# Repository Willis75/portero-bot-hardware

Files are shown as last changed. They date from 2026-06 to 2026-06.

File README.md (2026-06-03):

# Portero Bot — Hardware V2

Custom PCB and ESP32 firmware for the Claustro4 gate controller system.

## Overview

Replaces the Raspberry Pi Pico + protoboard + commercial relay board with a professional custom PCB.

- **MCU:** ESP32-WROOM-32E
- **Ethernet:** W5500 (SPI) + HanRun HR911105A RJ45
- **Relays:** 3× dry contact (simulates button press on gate opener controllers)
- **Power:** 9-24V DC barrel jack → 5V buck → 3.3V LDO
- **Programming:** MicroUSB (first flash) + OTA over Ethernet (updates)

## Repository Structure

```
hardware/       KiCad schematic + PCB layout + Gerber files
firmware/       PlatformIO ESP32 firmware (C++)
docs/           BOM, schematic reference, Flux.ai prompt
```

## API

The ESP32 exposes an HTTP API compatible with the existing Node.js bot (no changes required):

```
POST /abrir/vehicular_entrada
POST /abrir/vehicular_salida
POST /abrir/peatonal
GET  /healthz
POST /update   (OTA firmware upload)
```

## Related

- Bot: [Willis75/Portero-bot-telegram](https://github.com/Willis75/Portero-bot-telegram)
- Fabrication: JLCPCB PCBA (~$126 USD / 5 units)

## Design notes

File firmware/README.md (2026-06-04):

# portero-bot V2 firmware

Firmware ESP32 para hardware V2 (PCB custom con W5500 Ethernet + 3 relés).

## Setup primera vez

1. **Instalar PlatformIO**:
   ```
   pip install platformio
   ```
   O instalar extensión PlatformIO en VSCode.

2. **Crear `include/config.h`** copiando `config.example.h`:
   ```
   cp include/config.example.h include/config.h
   ```

3. **Llenar credenciales** en `include/config.h`:
   - `API_TOKEN`: generar con `openssl rand -hex 32`
   - `WIFI_SSID` / `WIFI_PASSWORD`: red WiFi backup
   - `ETH_STATIC_IP`: IP fija para Ethernet en la red del condominio
   - `OTA_USERNAME` / `OTA_PASSWORD`: para subir firmware OTA
   - `HEALTHCHECK_URL`: opcional (healthchecks.io)

4. **Build + flash via USB** (primera vez):
   ```
   cd firmware/
   pio run --target upload --upload-port COM4   # ajustar COM port
   pio device monitor
   ```

5. **Después flash via OTA** (sin desconectar):
   - Web UI: http://192.168.1.50/update
   - O CLI: `pio run --target upload --upload-protocol espota --upload-port 192.168.1.50`

## API HTTP

Todos los `POST` requieren header `Authorization: Bearer <API_TOKEN>`.

| Método | Endpoint | Función |
|---|---|---|
| POST | `/api/gate/entrada` | Activa relé K1 (portón entrada) |
| POST | `/api/gate/salida` | Activa relé K2 (portón salida) |
| POST | `/api/gate/peatonal` | Activa relé K3 (portón peatonal) |
| GET  | `/api/status` | Healthcheck JSON (uptime, IP, heap, rssi) |
| POST | `/api/restart` | Reset suave del ESP32 |
| GET  | `/update` | UI web OTA (basic auth) |

### Ejemplo curl

```bash
TOKEN="tu_token_de_32_bytes_hex"
curl -X POST -H "Authorization: Bearer $TOKEN" http://192.168.1.50/api/gate/entrada
# Response: {"status":"ok","gate":"entrada","uptime_s":12345}

curl http://192.168.1.50/api/status
# Response: {"uptime_s":12345,"eth":true,"wifi":false,"ip":"192.168.1.50","heap_free":234567,...}
```

## 24/7 Features

- **Brownout detector** (2.43V) → reset si rail 3.3V baja
- **Task Watchdog** (5s) → reset si firmware hang
- **Ethernet primary + WiFi fallback** automático
- **Static IP** (no depende DHCP)
- **Cooldown 2s** entre activaciones del mismo relé (evita re-trigger accidental)
- **Pulse 500ms** simula presión de botón
- **OTA con rollback** (AsyncElegantOTA)
- **Healthchecks.io ping** cada 60s para detectar offline

## Hardware pin map (NO modificar)

```
GPIO 32 → RELAY1 (entrada)
GPIO 33 → RELAY2 (salida)
GPIO 25 → RELAY3 (peatonal)
GPIO 5  → ETH_CS (W5500)
GPIO 18 → SPI_SCK
GPIO 19 → SPI_MISO
GPIO 23 → SPI_MOSI
GPIO 26 → ETH_INT
GPIO 27 → ETH_RST
GPIO 0  → BOOT (button SW1)
EN      → RESET (button SW2)
RX/TX 0 → UART debug (CH340 USB)
```

## Troubleshooting

- **Boot loop**: verificar VIN ≥ 9V, brownout detector activo
- **Ethernet not connecting**: revisar cable RJ45, link LED en magjack, ETH_RST cycle
- **WiFi only**: si Ethernet falla, firmware sigue por WiFi backup
- **OTA fails**: verificar partition table tiene OTA0 + OTA1 slots (16MB flash)

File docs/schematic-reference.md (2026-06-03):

# Portero Bot — Hardware V2 Schematic Document

**Fecha:** 2026-06-03  
**Versión:** 0.1 (draft para KiCad)  
**Fabricación:** JLCPCB PCBA  
**Dimensiones PCB sugeridas:** 100 × 80 mm, 2 capas

---

## BOM Completa (con LCSC part numbers)

| Ref | Componente | Valor / Parte | LCSC Part | Qty | Notas |
|-----|---|---|---|-----|---|
| U1 | MCU | ESP32-WROOM-32E | C473012 | 1 | Módulo, no chip pelón |
| U2 | Ethernet Controller | W5500 (LQFP-48) | C32843 | 1 | SPI full-hardware TCP/IP |
| U3 | USB-Serial | CH340C (SOP-16) | C84681 | 1 | Para primer flash + debug |
| U4 | LDO 3.3V | AMS1117-3.3 (SOT-223) | C6186 | 1 | Hasta 800mA |
| U5 | Buck 5V | MP2307DN (SOIC-8) | C14272 | 1 | 3A, 9-24V in → 5V out |
| J1 | Barrel Jack | DC-005 5.5×2.1mm | C16214 | 1 | Entrada poder 9-24V DC |
| J2 | Ethernet | HanRun HR911105A | C12074 | 1 | RJ45 + magnetics + LEDs |
| J3 | MicroUSB | MicroUSB tipo B | C10418 | 1 | Flash inicial + debug |
| J4 | Portón 1 | KF301-2P 5mm | C474883 | 1 | NO + COM (vehicular entrada) |
| J5 | Portón 2 | KF301-2P 5mm | C474883 | 1 | NO + COM (vehicular salida) |
| J6 | Portón 3 | KF301-2P 5mm | C474883 | 1 | NO + COM (peatonal) |
| J7 | UART Debug | Pin header 4p 2.54mm | C49661 | 1 | TX/RX/GND/3V3 |
| K1 | Relé Portón 1 | SRD-05VDC-SL-C | C35449 | 1 | 5V coil, contactos 30VDC/10A |
| K2 | Relé Portón 2 | SRD-05VDC-SL-C | C35449 | 1 | |
| K3 | Relé Portón 3 | SRD-05VDC-SL-C | C35449 | 1 | |
| OK1 | Optoacoplador 1 | PC817 (DIP-4) | C6786 | 1 | Aislamiento GPIO↔relé |
| OK2 | Optoacoplador 2 | PC817 (DIP-4) | C6786 | 1 | |
| OK3 | Optoacoplador 3 | PC817 (DIP-4) | C6786 | 1 | |
| Q1 | Transistor Relé 1 | 2N2222A (TO-92) | C164886 | 1 | Driver bobina relé |
| Q2 | Transistor Relé 2 | 2N2222A (TO-92) | C164886 | 1 | |
| Q3 | Transistor Relé 3 | 2N2222A (TO-92) | C164886 | 1 | |
| D1 | Flyback Relé 1 | 1N4148 (SOD-123) | C81598 | 1 | Protección bobina relé |
| D2 | Flyback Relé 2 | 1N4148 (SOD-123) | C81598 | 1 | |
| D3 | Flyback Relé 3 | 1N4148 (SOD-123) | C81598 | 1 | |
| D4 | Protección entrada | SS34 (SMA) | C8598 | 1 | Diodo Schottky en barril |
| D5 | TVS entrada | SMAJ24CA (SMA) | C17114 | 1 | Surge protection 24V |
| F1 | Fusible PTC | 1A reseteable (1812) | C70069 | 1 | Protección sobrecorriente |
| L1 | Inductor buck | 22µH (CDRH104R) | C338228 | 1 | Para MP2307 |
| X1 | Cristal W5500 | 25 MHz (SMD 5032) | C9002 | 1 | Reloj para W5500 |
| SW1 | Botón BOOT | Tact 3×4mm SMD | C318884 | 1 | ESP32 boot mode |
| SW2 | Botón RESET | Tact 3×4mm SMD | C318884 | 1 | EN pin ESP32 |
| LED1 | Power LED | Verde 0805 | C84256 | 1 | Indicador 3.3V presente |
| LED2 | Relé 1 LED | Rojo 0805 | C84260 | 1 | Indica relé activo |
| LED3 | Relé 2 LED | Rojo 0805 | C84260 | 1 | |
| LED4 | Relé 3 LED | Rojo 0805 | C84260 | 1 | |
| C1-C4 | Desacoplo ESP32 | 100nF (0402) | C1525 | 4 | VDD pins |
| C5-C8 | Desacoplo W5500 | 100nF (0402) | C1525 | 4 | VCC pins |
| C9 | Bulk ESP32 | 10µF (0805) | C15850 | 1 | |
| C10 | Bulk W5500 | 10µF (0805) | C15850 | 1 | |
| C11-C12 | Buck output | 100µF electrolítico | C144986 | 2 | |
| C13 | Buck input | 100µF electrolítico | C144986 | 1 | |
| C14-C15 | Cristal W5500 | 22pF (0402) | C1570 | 2 | Load caps |
| R1 | LED Power | 1kΩ (0402) | C11702 | 1 | |
| R2-R4 | LED Relés | 1kΩ (0402) | C11702 | 3 | |
| R5-R7 | Base transistor | 1kΩ (0402) | C11702 | 3 | GPIO → base Q1-Q3 |
| R8-R10 | Opto input | 330Ω (0402) | C11734 | 3 | LED del PC817 |
| R11-R16 | Pull-ups SPI | 10kΩ (0402) | C25744 | 6 | CS, INT, RST W5500 |
| R17 | USB D+ | 27Ω (0402) | C11702 | 1 | CH340C |
| R18 | USB D- | 27Ω (0402) | C11702 | 1 | CH340C |

---

## Asignación de Pines ESP32

### SPI → W5500
| ESP32 GPIO | W5500 Pin | Función |
|---|---|---|
| GPIO18 | SCLK | SPI Clock |
| GPIO23 | MOSI | SPI MOSI |
| GPIO19 | MISO | SPI MISO |
| GPIO5 | SCSn | Chip Select (activo LOW) |
| GPIO26 | INTn | Interrupt (activo LOW) |
| GPIO27 | RSTn | Reset (activo LOW) |

### Relés (a través de optoacopladores)
| ESP32 GPIO | Canal | Portón |
|---|---|---|
| GPIO32 | K1 | Vehicular Entrada |
| GPIO33 | K2 | Vehicular Salida |
| GPIO25 | K3 | Peatonal |

### USB Serial (CH340C)
| ESP32 GPIO | CH340C Pin |
|---|---|
| GPIO1 (TXD0) | RXD |
| GPIO3 (RXD0) | TXD |

### Control del ESP32
| Pin | Función |
|-----|---|
| EN | SW2 (RESET) + 10kΩ pull-up a 3.3V |
| GPIO0 | SW1 (BOOT) + 10kΩ pull-up a 3.3V |

### UART Debug Header (J7)
| Pin | Señal |
|-----|---|
| 1 | 3.3V |
| 2 | GND |
| 3 | GPIO1 (TX) |
| 4 | GPIO3 (RX) |

---

## Diagrama de Bloques — Conexiones

### Bloque 1: Power Supply

```
J1 (Barrel 9-24V DC)
  │
  ├── D4 (SS34 Schottky, polaridad)
  ├── D5 (SMAJ24CA TVS, surge)
  ├── F1 (PTC 1A)
  │
  └── VIN_RAW
        │
        ├── U5 (MP2307DN Buck)
        │     ├── L1 (22µH)
        │     ├── C11, C12 (100µF output)
        │     ├── C13 (100µF input)
        │     └── → VREG_5V (alimenta: K1/K2/K3 bobinas, CH340C, PC817 collectors)
        │
        └── VREG_5V
              └── U4 (AMS1117-3.3 LDO)
                    └── → VREG_3V3 (alimenta: ESP32, W5500, lógica)

LED1 (verde) con R1 (1kΩ) entre VREG_3V3 y GND — indicador power-on
```

### Bloque 2: ESP32-WROOM-32E

```
U1 (ESP32-WROOM-32E)
  ├── VDD (3.3V) — C1..C4 desacoplo 100nF a GND
  ├── GND
  ├── EN → 10kΩ pull-up a 3V3 + SW2 (RESET) a GND
  ├── GPIO0 → 10kΩ pull-up a 3V3 + SW1 (BOOT) a GND
  ├── GPIO1 (TXD0) → CH340C RXD + J7 pin 3
  ├── GPIO3 (RXD0) → CH340C TXD + J7 pin 4
  ├── GPIO5  → W5500 SCSn
  ├── GPIO18 → W5500 SCLK
  ├── GPIO19 → W5500 MISO
  ├── GPIO23 → W5500 MOSI
  ├── GPIO26 → W5500 INTn
  ├── GPIO27 → W5500 RSTn
  ├── GPIO32 → R5 (1kΩ) → Opto OK1 (Portón 1)
  ├── GPIO33 → R6 (1kΩ) → Opto OK2 (Portón 2)
  └── GPIO25 → R7 (1kΩ) → Opto OK3 (Portón 3)
```

### Bloque 3: W5500 Ethernet Controller

```
U2 (W5500 LQFP-48)
  ├── VCC (3.3V) — C5..C8 desacoplo 100nF a GND, C10 bulk 10µF
  ├── GND
  ├── SCLK ← GPIO18
  ├── MOSI ← GPIO23
  ├── MISO → GPIO19
  ├── SCSn ← GPIO5 (con R11 10kΩ pull-up a 3V3)
  ├── INTn → GPIO26 (con R12 10kΩ pull-up a 3V3)
  ├── RSTn ← GPIO27 (con R13 10kΩ pull-up a 3V3)
  ├── EXRES1 → 12.4kΩ a GND (referencia interna, requerido por datasheet)
  ├── X1/X2 → X1 cristal 25MHz (con C14, C15 22pF a GND)
  └── TPIN+/TPIN-/TPOUT+/TPOUT- → J2 (HanRun HR911105A magnetics integrados)

J2 (HanRun HR911105A)
  ├── Magnetics internos ya integrados — sin componentes externos adicionales
  ├── LED_LINK → indicador link Ethernet (integrado en magjack)
  └── LED_ACT  → indicador actividad (integrado en magjack)
```

### Bloque 4: USB-Serial CH340C

```
J3 (MicroUSB)
  ├── VBUS (5V) → no conectado a VREG_5V (alimentación independiente solo para flash)
  ├── D+ → R17 (27Ω) → CH340C UD+
  ├── D- → R18 (27Ω) → CH340C UD-
  └── GND

U3 (CH340C SOP-16)
  ├── VCC (3.3V)
  ├── GND
  ├── UD+ ← R17 desde USB D+
  ├── UD- ← R18 desde USB D-
  ├── TXD → ESP32 GPIO3 (RXD0)
  └── RXD ← ESP32 GPIO1 (TXD0)

Nota: CH340C tiene oscilador interno — no requiere cristal externo
```

### Bloque 5: Circuito de Relé (×3, idéntico por canal)

Ejemplo para Canal 1 (Portón Vehicular Entrada):

```
ESP32 GPIO32
  │
  R5 (1kΩ)
  │
  OK1 (PC817) — pin 1 (Ánodo LED)
  OK1         — pin 2 (Cátodo LED) → GND
  OK1         — pin 3 (Collector) → R8 (330Ω) → VREG_5V
  OK1         — pin 4 (Emitter)
  │
  R5_base: no necesario (ya R8 limita corriente)
  │
  Base de Q1 (2N2222A) ← Emitter de OK1
  Emitter de Q1 → GND
  Collector de Q1 → Bobina K1 (SRD-05VDC-SL-C)
  
  K1 bobina:
  ├── Pin + → VREG_5V
  ├── Pin - → Collector Q1
  └── D1 (1N4148) en antiparalelo (ánodo a collector, cátodo a 5V)

  K1 contactos:
  ├── COM → J4 Pin 1
  ├── NO  → J4 Pin 2
  └── NC  → no conectado

LED2 (rojo) con R2 (1kΩ) entre GPIO32 y GND — indicador visual relé activo
```

*Mismo circuito para K2/OK2/Q2/D2/LED3/J5 (GPIO33) y K3/OK3/Q3/D3/LED4/J6 (GPIO25)*

---

## Notas de Layout PCB (para el diseñador)

### Separación de planos
- **Zona A (lógica):** ESP32, W5500, CH340C, power supply — GND común
- **Zona B (potencia/relés):** K1-K3, borneras J4-J6 — mismo GND pero rutar lejos de zona A
- Los optoacopladores PC817 son la barrera física entre zonas A y B

### Routing crítico
- Trazas SPI (GPIO5/18/19/23 → W5500): mantener <5cm, paralelas, mismo largo aprox.
- Cristal X1 del W5500: lo más cerca posible al chip, sin cruzar otras trazas
- Magjack J2: rutar diferencial TPIN/TPOUT con impedancia 100Ω diferencial
- Decoupling caps (100nF): lo más cerca posible a cada pin VCC del chip

### Mecánica
- Borneras J4/J5/J6 en el borde de la PCB (acceso de cables desde exterior)
- Barrel jack J1 en esquina, también borde
- RJ45 J2 en borde
- MicroUSB J3 en borde
- SW1 (BOOT) y SW2 (RESET) accesibles sin desmontar de gabinete
- Header UART J7 accesible (para emergencias si OTA falla)
- 4 agujeros de montaje M3 en esquinas (3mm diámetro, pad de cobre para GND)

---

## Firmware — API HTTP (sin cambios respecto al Pico)

El ESP32 expone exactamente la misma API que el Pico actual. **Cero cambios en el bot Node.js.**

```
POST /abrir/vehicular_entrada   → cierra K1 (500ms pulso)
POST /abrir/vehicular_salida    → cierra K2 (500ms pulso)  
POST /abrir/peatonal            → cierra K3 (500ms pulso)
GET  /healthz                   → {"ok": true, "uptime": 12345}
POST /update                    → OTA firmware upload (AsyncElegantOTA)
```

**Stack firmware:**
- PlatformIO + Arduino-ESP32 framework
- `AsyncWebServer_ESP32_W5500` (Ethernet)
- `ESPAsyncWebServer` (HTTP)
- `AsyncElegantOTA` (OTA updates)
- LittleFS para config (IP, auth token)
- IP estática configurada en flash o DHCP reservation en router caseta

---

## Presupuesto estimado JLCPCB (5 unidades)

| Concepto | Costo USD |
|---|---|
| PCB (5 pcs, 2 capas, 100×80mm) | ~$5 |
| Assembly setup | ~$8 |
| Stencil | ~$8 |
| Componentes BOM (×5) | ~$75 |
| Shipping DHL a México | ~$30 |
| **Total** | **~$126 USD** |

Tiempo estimado: 7-10 días fab + 5-7 días envío = **~3 semanas**

---

## Pendientes antes de mandar a fabricar

- [ ] Confirmar el diseñador KiCad (Fiverr/Upwork o hazlo tú)
- [ ] Verificar stock de W5500 (C32843) en LCSC el día del pedido
- [ ] Confirmar dimensiones exactas del gabinete para ajustar PCB
- [ ] Definir si la IP del ESP32 va estática en firmware o por DHCP reservation
- [ ] Primera tirada: bench test OTA antes de instalar en caseta
- [ ] Actualizar `portero-health.sh` si cambia el endpoint de healthcheck

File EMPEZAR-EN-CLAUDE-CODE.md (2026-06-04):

# Cómo continuar en Claude Code

Todo el trabajo está en esta carpeta. Para seguir desde Claude Code:

## 1. Instalar Claude Code (si no lo tienes)
```bash
npm install -g @anthropic-ai/claude-code
```
(Requiere Node.js. Detalles: https://docs.claude.com/en/docs/claude-code)

## 2. Abrir el proyecto
Abre una terminal en esta carpeta y lanza Claude Code:
```bash
cd C:\Users\wumni\Documents\Proyectos\portero-bot-hardware
claude
```
Claude Code leerá automáticamente el archivo `CLAUDE.md` y tendrá todo el contexto
del proyecto (qué es, qué se hizo, qué falta).

## 3. Primer mensaje sugerido
Pega algo así para arrancar:

> Lee CLAUDE.md. Quiero terminar el rediseño del PCB en KiCad.
> Primero instala kicad-cli y corre el ERC sobre kicad/portero-bot-v2.kicad_sch
> para verificar la conectividad. Luego ayúdame con los pendientes 2–6 del CLAUDE.md.

## 4. Regenerar el esquemático (si haces cambios)
```bash
pip install kiutils openpyxl python-docx
python3 scripts/10_parse_edif.py
python3 scripts/20_build_master.py
python3 scripts/30_gen_schematic.py
```

## 5. Verificar de verdad la conectividad (lo que aquí no se pudo)
Claude Code puede instalar KiCad en tu máquina y correr:
```bash
kicad-cli sch erc kicad/portero-bot-v2.kicad_sch        # chequeo eléctrico
kicad-cli sch export netlist kicad/portero-bot-v2.kicad_sch   # exportar netlist
```

## Nota
- No hay una "exportación" automática del historial de este chat a Claude Code;
  lo que se transfiere es el proyecto (estos archivos), que es lo que importa.
- El `CLAUDE.md` cumple esa función: le da a Claude Code el contexto para continuar
  justo donde lo dejamos.
- Para guardar el avance en git:
  ```bash
  git add .
  git commit -m "Migración Flux→KiCad: esquemático reconstruido + scripts + revisión"
  ```

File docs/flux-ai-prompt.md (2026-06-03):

# Flux.ai Prompt — Portero Bot PCB V2

Copia y pega esto en Flux.ai al crear un nuevo proyecto.

---

Design a 2-layer PCB (100×80mm) for a gate controller system with the following specs:

## Overview
IoT gate controller with Ethernet connectivity. Controls 3 relay channels (dry contact / button simulation for gate openers). Programmed via USB initially, then OTA over Ethernet.

## Main Components

- **MCU:** ESP32-WROOM-32E module
- **Ethernet:** W5500 (LQFP-48) via SPI + HanRun HR911105A RJ45 magjack (integrated magnetics)
- **USB-Serial:** CH340C (SOP-16) on MicroUSB connector
- **Power:** Barrel jack DC 9-24V input → MP2307DN buck converter (5V/3A) → AMS1117-3.3 LDO (3.3V)
- **Relays:** 3× SRD-05VDC-SL-C (5V coil), each driven by PC817 optocoupler + 2N2222A transistor + 1N4148 flyback diode
- **Protection:** SS34 Schottky diode + SMAJ24CA TVS on barrel input + 1A PTC resettable fuse

## Pin Assignments (ESP32)

SPI to W5500:
- GPIO18 → SCLK
- GPIO23 → MOSI
- GPIO19 → MISO
- GPIO5  → SCSn (CS)
- GPIO26 → INTn
- GPIO27 → RSTn

Relay channels:
- GPIO32 → Relay 1 (via optocoupler PC817)
- GPIO33 → Relay 2 (via optocoupler PC817)
- GPIO25 → Relay 3 (via optocoupler PC817)

UART (USB-Serial CH340C):
- GPIO1 (TXD0) → CH340C RXD
- GPIO3 (RXD0) → CH340C TXD

Control:
- EN pin → 10kΩ pull-up to 3.3V + reset button to GND
- GPIO0  → 10kΩ pull-up to 3.3V + boot button to GND

## Power Architecture

```
Barrel Jack (9-24V) → SS34 → SMAJ24CA TVS → PTC 1A fuse
  → MP2307DN buck (22µH inductor, 2×100µF out) → 5V rail
    → AMS1117-3.3 LDO → 3.3V rail

5V powers: relay coils (K1/K2/K3), CH340C VCC, PC817 collector side
3.3V powers: ESP32-WROOM-32E, W5500, logic
```

## Relay Circuit (repeat ×3, identical)

```
ESP32 GPIO → 1kΩ resistor → PC817 LED anode
PC817 LED cathode → GND
PC817 collector → 330Ω → 5V
PC817 emitter → 2N2222A base
2N2222A emitter → GND
2N2222A collector → relay coil (−)
Relay coil (+) → 5V
1N4148 flyback diode across relay coil (anode at collector, cathode at 5V)
Relay NO + COM contacts → 2-pin screw terminal (KF301-2P, 5mm pitch)
Red LED + 1kΩ from GPIO to GND (relay status indicator)
```

## W5500 Ethernet Circuit

- W5500 powered at 3.3V, decoupling: 4×100nF + 10µF bulk
- 25MHz crystal with 22pF load caps on X1/X2
- EXRES1 pin → 12.4kΩ to GND (required by datasheet)
- SPI lines with 10kΩ pull-ups on SCSn, INTn, RSTn
- Differential pairs TPIN+/TPIN− and TPOUT+/TPOUT− routed to HR911105A magjack
- Route differential pairs at 100Ω differential impedance

## Connectors (all on PCB edges)

- J1: DC-005 barrel jack (9-24V in) — corner
- J2: HanRun HR911105A RJ45 magjack — edge
- J3: MicroUSB type B — edge
- J4/J5/J6: KF301-2P 5mm screw terminals (relay outputs, one per gate) — edge
- J7: 4-pin 2.54mm header (3.3V / GND / TX / RX) — debug UART
- SW1: boot button (GPIO0 to GND)
- SW2: reset button (EN to GND)

## Indicators

- LED1: green, power-on (3.3V rail, 1kΩ series)
- LED2/3/4: red, relay active status (one per channel, 1kΩ series from GPIO)

## Layout Guidelines

- Separate ground planes: logic zone (ESP32, W5500, CH340C) vs power zone (relays, screw terminals). PC817 optocouplers are the galvanic barrier between zones.
- Keep SPI traces short (<5cm), matched length
- Place 25MHz crystal as close as possible to W5500, no crossing traces
- Decoupling caps as close as possible to each VCC pin
- 4× M3 mounting holes in corners (copper-poured GND pad)
- Silkscreen labels on screw terminals: "ENTRADA / SALIDA / PEATONAL"
- Silkscreen label for barrel jack polarity (+ center)

## JLCPCB PCBA Notes

- All components available in LCSC catalog
- Prefer JLCPCB "Basic Parts" where possible to minimize extended part fees
- Key LCSC part numbers:
  - ESP32-WROOM-32E: C473012
  - W5500: C32843
  - CH340C: C84681
  - MP2307DN: C14272
  - AMS1117-3.3: C6186
  - HR911105A: C12074
  - SRD-05VDC-SL-C: C35449
  - PC817: C6786

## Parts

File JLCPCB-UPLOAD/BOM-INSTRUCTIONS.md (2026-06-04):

# BOM Instructions — Portero Bot V2 para JLCPCB

## Paso 1: Marcar THT como DNP

Estos componentes NO van a JLCPCB Assembly (tú los soldarás manual):

```
Q1, Q2, Q3, K1, K2, K3, J1, J3, J4, J5, J6, J7, F1, SW1, SW2, J2
```

En BOM editado para JLCPCB, eliminar estas filas (mover a hoja "Manual Assembly").

## Paso 2: Buscar LCSC# en JLCPCB Parts Library

URL: https://jlcpcb.com/parts

Para cada componente SMD:
1. Pegar el valor o nombre en el search
2. Filtrar por:
   - Library type: **Basic** primero (ahorra $3 setup fee), Extended si no hay
   - Package/footprint: debe matchear (ej. 0603, 1210, SOIC-8, etc.)
   - Stock: >100 unidades
3. Copiar el `C#####` (LCSC Part Number)
4. Pegar en columna LCSC del BOM CSV

## Paso 3: Componentes críticos a buscar EXACTO

```
U1 ESP32-WROOM-32E-N16    → Buscar EXACT "ESP32-WROOM-32E-N16"
                            Verificar N16 (16MB flash, no N8 ni N4)
U2 W5500                  → WIZnet, package LQFP-48
U3 CH340C                 → WCH, SOIC-16, no CH340G ni CH340N
U4, U5 MP2307DN           → MPS Semi, package SOIC-8 EP
                            CRÍTICO: verificar versión "DN-HW-LF-Z"
Y1 25MHz crystal 3225     → 4 pads, ±20ppm tolerance ok
D1 SS34                   → Schottky 3A 40V, SMA
D2 SMAJ24CA               → TVS bidirectional 24V, SMA
D3,4,5 1N4148WS           → SOD-323, fast switching
ISO1-3 PC817              → DIP-4 (NO SOP-4), Sharp/Lite-On
```

## Paso 4: Footprints comunes (Basic Parts típicos)

| Valor | Footprint | LCSC search |
|---|---|---|
| Resistencias 0603 1% | 0603 | "R 0603 1% [valor]" |
| Cap 100nF 0603 X7R | 0603 | "100nF 0603 50V X7R" |
| Cap 100uF 1210 X5R | 1210 | "100uF 1210 X5R" |
| LED 0603 verde | 0603 | "LED 0603 green" |
| LED 0603 rojo | 0603 | "LED 0603 red" |

## Paso 5: Verificación final

Antes de subir BOM a JLCPCB:
- [ ] Todas las filas SMD tienen LCSC# (excepto DNP)
- [ ] No quedan "Extended Parts" sin necesidad (cada uno = $3 setup)
- [ ] Stock confirmado en JLCPCB (>30 unidades por componente)
- [ ] Quantity para 5 PCBs: multiplicar refs (ej. 8 resistores * 5 = 40 ud)

## Paso 6: Subir a JLCPCB

1. Order PCB → Upload `portero-bot-v2-GERBERS.zip`
2. PCB Specs:
   - Layers: **2**
   - Dimensions: 117.5 × 104.5 mm (auto-detect del Gerber)
   - Thickness: 1.6mm
   - Solder mask: green (cheapest)
   - Surface finish: HASL lead-free (cheapest) o ENIG (mejor para SMD)
   - Quantity: 5
3. Assembly Service:
   - Enable PCB Assembly
   - Side: Top only (componentes solo F.Cu)
   - Quantity: 5
   - Upload BOM (CSV) + CPL (CSV)
4. Confirm parts → revisar matches → checkout

## Costos esperados

- 5 PCBs (sin assembly): ~$10 + shipping ~$25 = $35
- 5 PCBs con SMD assembly: ~$80-120 según extended parts
- Setup fees: $8 stencil + $0.0017/joint * ~200 joints = $0.34
- Total ~$45-130

## Mi paste-friendly template ya casi listo

Si quieres, te genero un script que toma tu `docs/Portero-Bot-V2_BOM-revisado.xlsx` (que ya tiene LCSC#) y lo mergea con este CSV automaticamente.

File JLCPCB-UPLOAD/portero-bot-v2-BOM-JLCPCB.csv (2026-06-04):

Comment | Designator | Footprint | LCSC Part #
0ZCC0150BF2C | F1 | Fuse_1206_3216Metric | C315895
100nF | C10,C11,C2,C3,C6,C7,C8,C9 | C_0603_1608Metric | C14663
100nF | C22,C23 | C_1210_3225Metric | C141218
100uF | C16,C17,C20,C21 | C_1210_3225Metric | C2840614
10k | R1,R2,R23,R25,R4,R5,R6 | R_0603_1608Metric | C25804
10nF | C5 | C_0603_1608Metric | C57112
12.4k | R3 | R_0603_1608Metric | C22865
1N5819WS-7-F | D3,D4,D5 | D_SOD-323 | C8598
1k | R13,R26,R7,R8,R9 | R_0603_1608Metric | C21190
1uF | C1 | C_0603_1608Metric | C15849
22pF | C14,C15 | C_0603_1608Metric | C1653
22uH | L1,L2 | L_6.3x6.3_H3 | C354622
26.1k | R22 | R_0603_1608Metric | C23356
2N2222A | Q1,Q2,Q3 | TO-92_Inline | C8327
330 | R19,R20,R21 | R_0603_1608Metric | C23138
4.7uF | C4 | C_0603_1608Metric | C19666
44.2k | R24 | R_0603_1608Metric | C23056
CH340C | U3 | SOIC-16_3.9x9.9mm_P1.27mm | C84681
DC005 | J1 | BarrelJack_Horizontal | C431533
ESP32-WROOM-32E-N16 | U1 | ESP32-WROOM-32 | C701343
HR911105A | J2 | RJ45_Hanrun_HR911105A_Horizontal | C12074
KF301-2P | J4,J5,J6 | TerminalBlock_Phoenix_MKDS-3-2-5.08_1x02_P5.08mm_Horizontal | C474881
KH-6X6X5H-STM | SW1,SW2 | SW_Push_SPST_NO_Alps_SKRK | C318884
KT-0603R | LED5 | LED_0603_1608Metric | C2286
KT-0603YG | LED1 | LED_0603_1608Metric | C2289
MP2307DN-HW-LF-Z | U4,U5 | SOIC-8-1EP_3.9x4.9mm_P1.27mm_EP2.29x3mm | C18921
NX3225GA-25MHZ-STD-CRG-2 | Y1 | Crystal_SMD_3225-4Pin_3.2x2.5mm | C438901
PC817X1CSP9F | ISO1,ISO2,ISO3 | DIP-4_W7.62mm | C3025068
Pin Header 01x04 2.54mm Vertical | J7 | PinHeader_1x04_P2.54mm_Vertical | C124378
SMAJ24CA-TR | D2 | D_SMA | C148223
SRD-05VDC-SL-C | K1,K2,K3 | Relay_SPDT_SANYOU_SRD_Series_Form_C | C35449
SS34-E3/57T | D1 | D_SMA | C8678
USB Micro B | J3 | USB_Micro-B_Wuerth_614105150721_Vertical | C46390
W5500 | U2 | LQFP-48_7x7mm_P0.5mm | C32843

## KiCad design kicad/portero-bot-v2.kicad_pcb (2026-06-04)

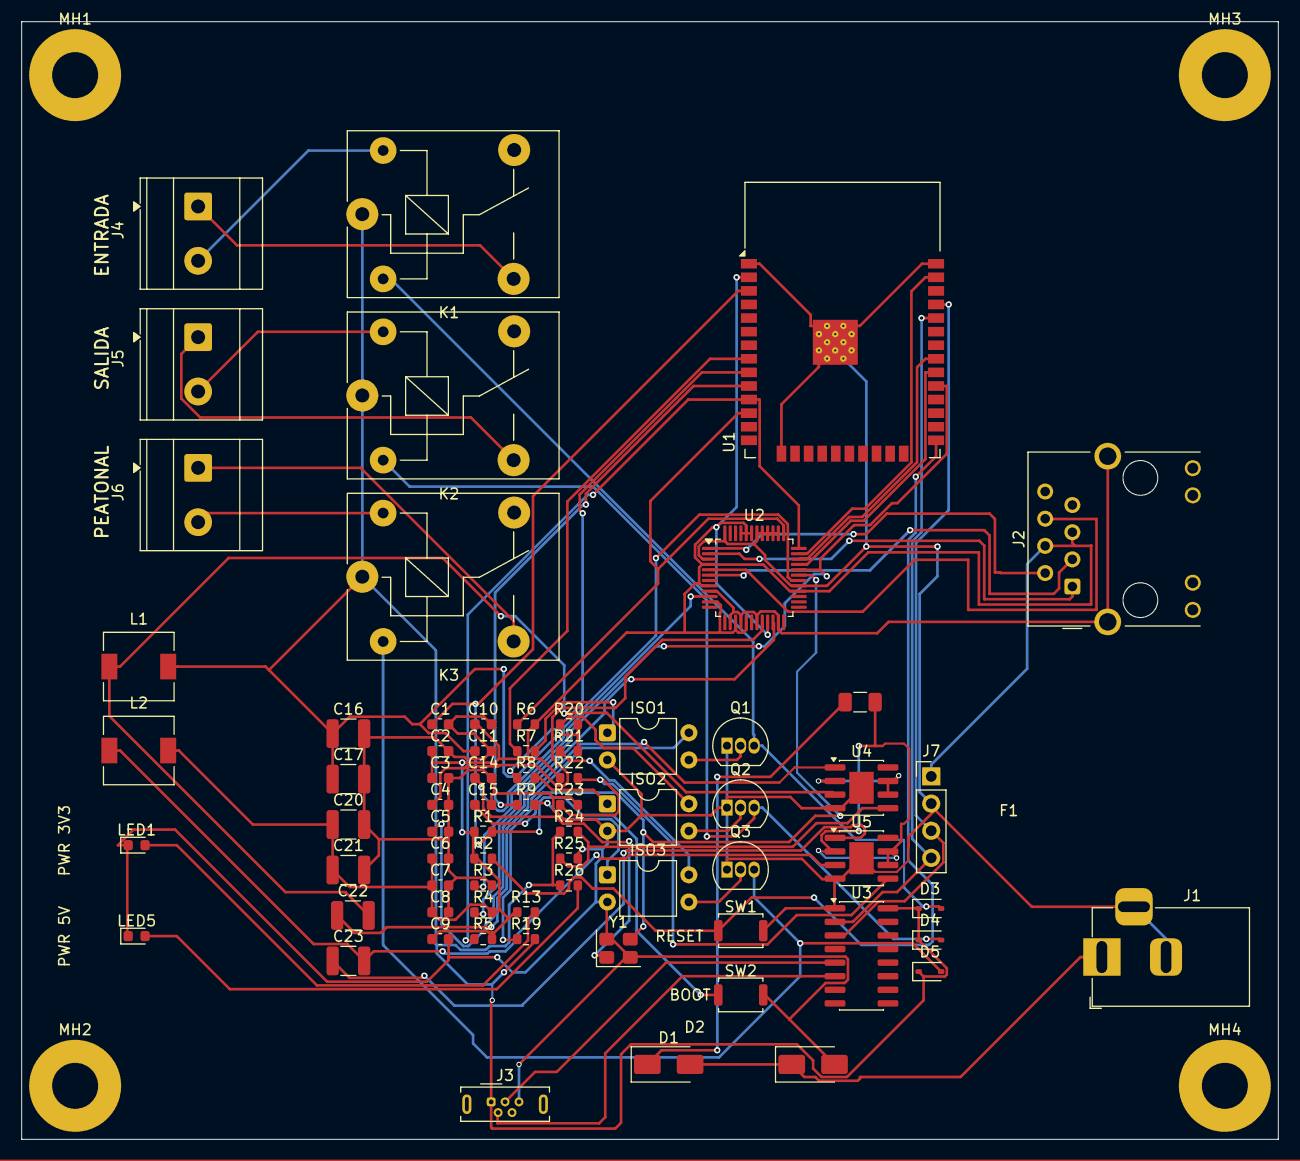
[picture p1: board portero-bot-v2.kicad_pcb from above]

Board: 2 copper layers, 117.5 x 104.5 mm, 75 parts (0 on the bottom side), 56 nets.

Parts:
C1: 1uF; C_0603_1608Metric
C2, C3, C6, C7, C8, C9, C10, C11: 100nF; C_0603_1608Metric
C4: 4.7uF; C_0603_1608Metric
C5: 10nF; C_0603_1608Metric
C14, C15: 22pF; C_0603_1608Metric
C16, C17, C20, C21: 100uF; C_1210_3225Metric
C22, C23: 100nF; C_1210_3225Metric
D1: SS34-E3/57T; D_SMA
D2: SMAJ24CA-TR; D_SMA
D3, D4, D5: 1N5819WS-7-F; D_SOD-323
F1: 0ZCC0150BF2C; Fuse_1206_3216Metric
ISO1, ISO2, ISO3: PC817X1CSP9F; DIP-4_W7.62mm
J1: DC005; BarrelJack_Horizontal
J2: HR911105A; RJ45_Hanrun_HR911105A_Horizontal
J3: USB Micro B; USB_Micro-B_Wuerth_614105150721_Vertical
J4, J5, J6: KF301-2P; TerminalBlock_Phoenix_MKDS-3-2-5.08_1x02_P5.08mm_Horizontal
J7: Pin Header 01x04 2.54mm Vertical; PinHeader_1x04_P2.54mm_Vertical
K1, K2, K3: SRD-05VDC-SL-C; Relay_SPDT_SANYOU_SRD_Series_Form_C
L1, L2: 22uH; L_6.3x6.3_H3
LED1: KT-0603YG; LED_0603_1608Metric
LED5: KT-0603R; LED_0603_1608Metric
MH1, MH2, MH3, MH4: MountingHole_4.3mm_M4_Pad
Q1, Q2, Q3: 2N2222A; TO-92_Inline
R1, R2, R4, R5, R6, R23, R25: 10k; R_0603_1608Metric
R3: 12.4k; R_0603_1608Metric
R7, R8, R9, R13, R26: 1k; R_0603_1608Metric
R19, R20, R21: 330; R_0603_1608Metric
R22: 26.1k; R_0603_1608Metric
R24: 44.2k; R_0603_1608Metric
SW1, SW2: KH-6X6X5H-STM; SW_Push_SPST_NO_Alps_SKRK
U1: ESP32-WROOM-32E-N16; ESP32-WROOM-32
U2: W5500; LQFP-48_7x7mm_P0.5mm
U3: CH340C; SOIC-16_3.9x9.9mm_P1.27mm
U4, U5: MP2307DN-HW-LF-Z; SOIC-8-1EP_3.9x4.9mm_P1.27mm_EP2.29x3mm
Y1: NX3225GA-25MHZ-STD-CRG-2; Crystal_SMD_3225-4Pin_3.2x2.5mm

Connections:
3V3: C2.1, C3.1, C6.1, C7.1, C8.1, C9.1, C10.1, C20.1, C21.1, J2.4, J2.5, J7.1, L2.2, R1.1, R2.1, R4.2, R5.2, R6.2, R13.1, R22.1, U1.2 (3V3), U2.4 (AVDD), U2.8 (AVDD), U2.11 (AVDD), U2.15 (AVDD), U2.17 (AVDD), U2.21 (AVDD), U2.28 (VDD), U2.43 (PMODE2), U2.44 (PMODE1), U2.45 (PMODE0)
5V: C11.1, C16.1, C17.1, D3.1 (K), D4.1 (K), D5.1 (K), J3.1 (VBUS), K1.1 (A1), K2.1 (A1), K3.1 (A1), L1.2, R19.2, R20.2, R21.2, R24.1, R26.1, U3.16 (VCC)
BOOT: R2.2, SW1.1, U1.25 (IO0)
BST_3V3: C23.1, U5.1 (BS)
BST_5V: C22.1, U4.1 (BS)
EN: C1.1, R1.2, SW2.1, U1.3 (EN)
ETH_CS: R4.1, U1.29 (IO5), U2.32 (~SCS)
ETH_INT: R5.1, U1.11 (IO26), U2.36 (~INT)
ETH_RST: R6.1, U1.12 (IO27), U2.37 (~RST)
ETH_RX_N: J2.6, U2.5 (RXN)
ETH_RX_P: J2.3, U2.6 (RXP)
ETH_TX_N: J2.2, U2.1 (TXN)
ETH_TX_P: J2.1, U2.2 (TXP)
ETH_XI: C14.1, U2.30 (XI/CLKIN), Y1.1
ETH_XO: C15.1, U2.31 (XO), Y1.3
FB_3V3: R22.2, R23.1, U5.5 (FB)
FB_5V: R24.2, R25.1, U4.5 (FB)
GND: C1.2, C2.2, C3.2, C4.2, C5.2, C6.2, C7.2, C8.2, C9.2, C10.2, C11.2, C14.2, C15.2, C16.2, C17.2, C20.2, C21.2, D2.2, ISO1.2 (CATHODE), ISO2.2 (CATHODE), ISO3.2 (CATHODE), J1.2, J1.3, J2.SH, J3.5 (GND), J7.2, LED1.1, LED5.1, Q1.1 (E), Q2.1 (E), Q3.1 (E), R3.2, R23.2, R25.2, SW1.2, SW2.2, U1.1 (GND), U1.15 (GND), U1.38 (GND), U1.39 (GND), U2.3 (AGND), U2.9 (AGND), U2.14 (AGND), U2.16 (AGND), U2.19 (AGND), U2.23 (RSVD), U2.29 (GND), U2.38 (RSVD), U2.39 (RSVD), U2.40 (RSVD), U2.41 (RSVD), U2.42 (RSVD), U2.48 (AGND), U3.1 (GND), U4.4 (GND), U4.9 (EPAD), U5.4 (GND), U5.9 (EPAD), Y1.2 (GND), Y1.4 (GND)
LED5_5V_IND: LED5.2, R26.2
LED_3V3_PWR: LED1.2, R13.2
RELAY1_BASE: ISO1.3 (EMITTER), Q1.2 (B)
RELAY1_COIL_LOW: D3.2 (A), K1.2 (A2), Q1.3 (C)
RELAY1_COM: J4.1, K1.3 (COM)
RELAY1_GPIO: R7.1, U1.8 (IO32)
RELAY1_NO: J4.2, K1.5 (NO)
RELAY1_OPTO_COL: ISO1.4 (COLLECTOR), R19.1
RELAY1_OPTO_LED: ISO1.1 (ANODE), R7.2
RELAY2_BASE: ISO2.3 (EMITTER), Q2.2 (B)
RELAY2_COIL_LOW: D4.2 (A), K2.2 (A2), Q2.3 (C)
RELAY2_COM: J5.1, K2.3 (COM)
RELAY2_GPIO: R8.1, U1.9 (IO33)
RELAY2_NO: J5.2, K2.5 (NO)
RELAY2_OPTO_COL: ISO2.4 (COLLECTOR), R20.1
RELAY2_OPTO_LED: ISO2.1 (ANODE), R8.2
RELAY3_BASE: ISO3.3 (EMITTER), Q3.2 (B)
RELAY3_COIL_LOW: D5.2 (A), K3.2 (A2), Q3.3 (C)
RELAY3_COM: J6.1, K3.3 (COM)
RELAY3_GPIO: R9.1, U1.10 (IO25)
RELAY3_NO: J6.2, K3.5 (NO)
RELAY3_OPTO_COL: ISO3.4 (COLLECTOR), R21.1
RELAY3_OPTO_LED: ISO3.1 (ANODE), R9.2
SPI_MISO: U1.31 (IO19), U2.34 (MISO)
SPI_MOSI: U1.37 (IO23), U2.35 (MOSI)
SPI_SCLK: U1.30 (IO18), U2.33 (SCLK)
SW_BUCK: C22.2, L1.1, U4.3 (SW)
SW_BUCK_3V3: C23.2, L2.1, U5.3 (SW)
UART0_RX: J7.4, U1.34 (RXD0), U3.2 (TXD)
UART0_TX: J7.3, U1.35 (TXD0), U3.3 (RXD)
USB_D_N: J3.2 (D-), U3.6 (UD-)
USB_D_P: J3.3 (D+), U3.5 (UD+)
VIN_BUCK: F1.2, U4.2 (IN), U4.6, U4.7 (EN), U5.2 (IN), U5.6, U5.7 (EN)
VIN_PROT: D1.1 (K), F1.1
VIN_RAW: D1.2 (A), D2.1, J1.1
W5500_1V2O: C5.1, U2.22 (1V2O)
W5500_EXRES: R3.1, U2.10 (EXRES1)
W5500_TOCAP: C4.1, U2.20 (TOCAP)

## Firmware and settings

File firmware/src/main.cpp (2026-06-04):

// portero-bot-v2 firmware
// ESP32-WROOM-32E + W5500 Ethernet + 3 reles SRD-05VDC
// HTTP API + OTA + WiFi fallback

#include <Arduino.h>
#include <SPI.h>
#include <ETH.h>
#include <WiFi.h>
#include <HTTPClient.h>
#include <ESPAsyncWebServer.h>
#include <ElegantOTA.h>
#include <esp_task_wdt.h>

#if __has_include("config.h")
  #include "config.h"
#else
  #include "config.example.h"
  #warning "Using config.example.h — crea include/config.h con tus credenciales"
#endif

// === Globals ===
AsyncWebServer server(HTTP_PORT);
volatile bool ethConnected = false;
volatile bool wifiConnected = false;
unsigned long lastRelayActivation[3] = {0, 0, 0};
unsigned long lastHealthcheck = 0;
unsigned long bootTime = 0;

const char* GATE_NAMES[3] = {"entrada", "salida", "peatonal"};
const int GATE_PINS[3] = {PIN_RELAY_ENTRADA, PIN_RELAY_SALIDA, PIN_RELAY_PEATONAL};

// === Ethernet event handler ===
void onEthEvent(arduino_event_id_t event) {
  switch (event) {
    case ARDUINO_EVENT_ETH_START:
      log_i("ETH started");
      ETH.setHostname("portero-bot");
      break;
    case ARDUINO_EVENT_ETH_CONNECTED:
      log_i("ETH connected (link up)");
      break;
    case ARDUINO_EVENT_ETH_GOT_IP:
      log_i("ETH IP: %s", ETH.localIP().toString().c_str());
      ethConnected = true;
      break;
    case ARDUINO_EVENT_ETH_DISCONNECTED:
      log_w("ETH disconnected");
      ethConnected = false;
      break;
    case ARDUINO_EVENT_ETH_STOP:
      log_w("ETH stopped");
      ethConnected = false;
      break;
    default:
      break;
  }
}

// === WiFi event handler ===
void onWiFiEvent(arduino_event_id_t event) {
  switch (event) {
    case ARDUINO_EVENT_WIFI_STA_GOT_IP:
      log_i("WiFi IP: %s", WiFi.localIP().toString().c_str());
      wifiConnected = true;
      break;
    case ARDUINO_EVENT_WIFI_STA_DISCONNECTED:
      log_w("WiFi disconnected, reconnecting...");
      wifiConnected = false;
      WiFi.reconnect();
      break;
    default:
      break;
  }
}

// === Setup helpers ===
void setupRelays() {
  for (int i = 0; i < 3; i++) {
    pinMode(GATE_PINS[i], OUTPUT);
    digitalWrite(GATE_PINS[i], LOW);  // Idle = LOW (opto LED off, BJT off, coil off)
  }
}

void setupEthernet() {
  WiFi.onEvent(onEthEvent);
  // W5500 via SPI on ESP32 (Arduino ESP32 core 2.0.5+)
  SPI.begin(PIN_SPI_SCK, PIN_SPI_MISO, PIN_SPI_MOSI, PIN_ETH_CS);
  if (!ETH.begin(ETH_PHY_W5500, 1, PIN_ETH_CS, PIN_ETH_INT, PIN_ETH_RST,
                 SPI3_HOST, 14000000, PIN_SPI_SCK, PIN_SPI_MISO, PIN_SPI_MOSI)) {
    log_e("ETH.begin() failed!");
    return;
  }
  if (ETH_USE_STATIC_IP) {
    IPAddress ip, gw, sn, dns1, dns2;
    ip.fromString(ETH_STATIC_IP);
    gw.fromString(ETH_GATEWAY);
    sn.fromString(ETH_SUBNET);
    dns1.fromString(ETH_DNS1);
    dns2.fromString(ETH_DNS2);
    ETH.config(ip, gw, sn, dns1, dns2);
  }
}

void setupWiFi() {
  if (!WIFI_ENABLED) return;
  WiFi.onEvent(onWiFiEvent);
  WiFi.mode(WIFI_STA);
  WiFi.setHostname("portero-bot");
  WiFi.begin(WIFI_SSID, WIFI_PASSWORD);
  log_i("WiFi connecting to %s...", WIFI_SSID);
}

// === Auth ===
bool checkAuth(AsyncWebServerRequest* request) {
  if (!request->hasHeader("Authorization")) return false;
  String auth = request->header("Authorization");
  String expected = "Bearer " + String(API_TOKEN);
  return auth == expected;
}

// === Gate activation ===
bool activateGate(int idx) {
  if (idx < 0 || idx >= 3) return false;
  unsigned long now = millis();
  if (now - lastRelayActivation[idx] < RELAY_COOLDOWN_MS) {
    log_w("Gate %s: cooldown active (%lums ago)", GATE_NAMES[idx], now - lastRelayActivation[idx]);
    return false;
  }
  log_i("Activating gate: %s", GATE_NAMES[idx]);
  digitalWrite(GATE_PINS[idx], HIGH);
  delay(RELAY_PULSE_MS);
  digitalWrite(GATE_PINS[idx], LOW);
  lastRelayActivation[idx] = millis();
  return true;
}

// === HTTP handlers ===
void handleGate(AsyncWebServerRequest* request, int idx) {
  if (!checkAuth(request)) {
    request->send(401, "application/json", "{\"error\":\"unauthorized\"}");
    return;
  }
  if (activateGate(idx)) {
    String resp = "{\"status\":\"ok\",\"gate\":\"" + String(GATE_NAMES[idx]) + "\",\"uptime_s\":" + String((millis() - bootTime) / 1000) + "}";
    request->send(200, "application/json", resp);
  } else {
    request->send(429, "application/json", "{\"error\":\"cooldown\"}");
  }
}

void handleStatus(AsyncWebServerRequest* request) {
  String json = "{";
  json += "\"uptime_s\":" + String((millis() - bootTime) / 1000) + ",";
  json += "\"eth\":" + String(ethConnected ? "true" : "false") + ",";
  json += "\"wifi\":" + String(wifiConnected ? "true" : "false") + ",";
  json += "\"ip\":\"" + (ethConnected ? ETH.localIP().toString() : (wifiConnected ? WiFi.localIP().toString() : String("none"))) + "\",";
  json += "\"mac\":\"" + (ethConnected ? ETH.macAddress() : WiFi.macAddress()) + "\",";
  json += "\"heap_free\":" + String(ESP.getFreeHeap()) + ",";
  json += "\"rssi\":" + String(WiFi.RSSI()) + ",";
  json += "\"last_activations\":{";
  for (int i = 0; i < 3; i++) {
    json += "\"" + String(GATE_NAMES[i]) + "\":" + String(lastRelayActivation[i] / 1000);
    if (i < 2) json += ",";
  }
  json += "}}";
  request->send(200, "application/json", json);
}

void handleRestart(AsyncWebServerRequest* request) {
  if (!checkAuth(request)) {
    request->send(401, "application/json", "{\"error\":\"unauthorized\"}");
    return;
  }
  request->send(200, "application/json", "{\"status\":\"restarting\"}");
  delay(500);
  ESP.restart();
}

void setupHttpServer() {
  server.on("/api/gate/entrada",  HTTP_POST, [](AsyncWebServerRequest* r){ handleGate(r, 0); });
  server.on("/api/gate/salida",   HTTP_POST, [](AsyncWebServerRequest* r){ handleGate(r, 1); });
  server.on("/api/gate/peatonal", HTTP_POST, [](AsyncWebServerRequest* r){ handleGate(r, 2); });
  server.on("/api/status",        HTTP_GET,  handleStatus);
  server.on("/api/restart",       HTTP_POST, handleRestart);
  server.on("/",                  HTTP_GET, [](AsyncWebServerRequest* r){
    r->send(200, "text/plain", "portero-bot V2 - see /api/status");
  });
  // OTA mounted on /update
  ElegantOTA.begin(&server, OTA_USERNAME, OTA_PASSWORD);
  server.begin();
  log_i("HTTP server listening on port %d", HTTP_PORT);
}

// === Healthcheck ping ===
void sendHealthcheck() {
  if (!HEALTHCHECK_ENABLED) return;
  if (!ethConnected && !wifiConnected) return;
  HTTPClient http;
  http.setTimeout(3000);
  http.begin(HEALTHCHECK_URL);
  int code = http.GET();
  log_d("Healthcheck ping: HTTP %d", code);
  http.end();
}

// === Watchdog ===
void setupWatchdog() {
  esp_task_wdt_init(WATCHDOG_TIMEOUT_S, true);
  esp_task_wdt_add(NULL);
}

// === Main ===
void setup() {
  Serial.begin(115200);
  delay(100);
  log_i("=== portero-bot V2 booting ===");
  log_i("Firmware: %s %s", __DATE__, __TIME__);
  log_i("Chip: %s rev %d, %d MHz", ESP.getChipModel(), ESP.getChipRevision(), getCpuFrequencyMhz());

  bootTime = millis();
  setupRelays();
  setupEthernet();
  setupWiFi();
  setupHttpServer();
  setupWatchdog();

  log_i("=== Boot complete ===");
}

void loop() {
  esp_task_wdt_reset();  // Pet the watchdog
  ElegantOTA.loop();

  // Periodic healthcheck ping
  if (millis() - lastHealthcheck > HEALTHCHECK_PERIOD_MS) {
    sendHealthcheck();
    lastHealthcheck = millis();
  }

  delay(100);
}

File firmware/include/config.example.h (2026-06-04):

#pragma once
// Copia este archivo a config.h y rellena con credenciales reales.
// config.h esta gitignored.

// === Network ===
// Static IP for Ethernet (preferir static para 24/7, no depende DHCP del router)
#define ETH_USE_STATIC_IP   true
#define ETH_STATIC_IP       "192.168.1.50"
#define ETH_GATEWAY         "192.168.1.1"
#define ETH_SUBNET          "255.255.255.0"
#define ETH_DNS1            "1.1.1.1"
#define ETH_DNS2            "8.8.8.8"

// WiFi backup (si Ethernet falla)
#define WIFI_ENABLED        true
#define WIFI_SSID           "TU_WIFI_SSID"
#define WIFI_PASSWORD       "TU_WIFI_PASSWORD"

// === Auth ===
// Token Bearer para autenticar requests HTTP
// Generate: openssl rand -hex 32
#define API_TOKEN           "REEMPLAZA_CON_TOKEN_HEX_32_BYTES"

// === OTA ===
#define OTA_USERNAME        "admin"
#define OTA_PASSWORD        "REEMPLAZA_CON_PASS_FUERTE"

// === Healthchecks.io (opcional - heartbeat externo) ===
#define HEALTHCHECK_ENABLED true
#define HEALTHCHECK_URL     "https://hc-ping.com/REEMPLAZA-CON-UUID"
#define HEALTHCHECK_PERIOD_MS  60000  // 60 segundos

// === Hardware: pin assignments (NO cambiar - hardware fijo V2) ===
// ESP32-WROOM-32E -> W5500 SPI
#define PIN_ETH_CS          5
#define PIN_ETH_INT         26
#define PIN_ETH_RST         27
#define PIN_SPI_SCK         18
#define PIN_SPI_MISO        19
#define PIN_SPI_MOSI        23

// Reles (GPIO output)
#define PIN_RELAY_ENTRADA   32  // K1 - portón entrada
#define PIN_RELAY_SALIDA    33  // K2 - portón salida
#define PIN_RELAY_PEATONAL  25  // K3 - portón peatonal

// LEDs indicadores (en hardware solo LED1=3V3 y LED5=5V; ningun GPIO controla LED)
// LEDs son indicadores power-on directamente conectados al rail

// === Timing ===
#define RELAY_PULSE_MS      500     // Duracion del cierre de contacto (simula presionar botón)
#define RELAY_COOLDOWN_MS   2000    // Tiempo minimo entre activaciones del mismo relé
#define WATCHDOG_TIMEOUT_S  5       // Task watchdog
#define HTTP_PORT           80

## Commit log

2026-06-03 init: estructura base repo hardware V2
    BOM completo, asignación de pines ESP32+W5500, circuito de relés con
    optoacopladores, prompt Flux.ai para generación de esquemático KiCad.
2026-06-03 fix: footprints KiCad10 + C2-C11 100nF + encoding UTF-8
    - Footprints corregidos a nombres reales de KiCad 10:
    HR911105A, SOIC-8-1EP, relay SANYOU SRD, MicroUSB Wuerth,
    TerminalBlock Phoenix, SW Alps SKRK, inductor L_6.3x6.3_H3
    - C2,C3,C6-C11: 100uF→100nF (caps de desacople, error de Flux)
    - open() con encoding=utf-8 en scripts (fix Windows cp1252)
    - ERC: 0 errores, 410 warnings cosmeticos
    [portero-bot-v2.kicad_sch]
2026-06-03 feat(pcb): silkscreen, Edge.Cuts, LEDs corregidos, refs normalizadas
    - 13 etiquetas gr_text en F.SilkS (BOOT/RESET/3V3/5V/ENTRADA/SALIDA/PEATONAL)
    - Edge.Cuts 117.5x104.5mm via pcbnew SHAPE_T_RECT
    - .kicad_dru: drill minimo 0.2mm para vias termicas ESP32
    - LEDs: footprint inductor->LED_0603_1608Metric (5 componentes)
    - Referencias normalizadas: LED1-5, SW1-2, J4-6, MH1-4 (requerido para freerouting DSN)
    - Net "Net 2" renombrada a VIN_FUSED
    - DRC: 0 errores reales, 170 unconnected (ruteo pendiente)
    [portero-bot-v2.kicad_pcb, portero-bot-v2.kicad_sch]
2026-06-04 feat(pcb): rute RELAY1_GPIO/BOOT/BST_5V con A* multilayer, 0 unconnected
    3 redes ruteadas programáticamente con A* sobre grid 0.5mm en F.Cu+B.Cu:
    - RELAY1_GPIO (R7.1 ↔ U1.8): 4 vías, 23 segmentos
    - BOOT (R2.2 ↔ SW1.1 ↔ U1.25): 4 vías, 59 segmentos
    - BST_5V (C22.1 ↔ U4.1): 6 vías, 23 segmentos
    Verificador con line-segment intersection + circle distance evita shorts,
    respeta keep-out antena ESP32 (x=122.25-170.25, y=47.145-68.085).
    Eliminados componentes (script 59) según pedido del cliente:
    - LED2, LED3, LED4 (indicadores de relé)
    - R10, R11, R12 (resistencias series de los LEDs)
    DRC: 300 → 100 violations (0 unconnected, 0 shorts, 0 keep-out hits,
    0 tracks_crossing). Restan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
    [portero-bot-v2.kicad_pcb]
2026-06-04 feat(pcb): re-ruteo completo con freerouting v2.2.4, DRC 100% limpio
    - Netclass Default: añade via_diameter 0.6mm + via_drill 0.3mm + clearance 0.10mm
    (fix bug que generaba 79 shorts: KiCad exportaba vias -0.001mm sin estas dims)
    - Re-routing freerouting v2.2.4 (Java 25): 191 nets, 0 unrouted en pass #10
    - DRC: 0 violations, 0 unconnected, 0 footprint errors
    - 928 trazas/vías totales
    - scripts/60_clean_and_export_dsn.py: wipe tracks/vias + ExportSpecctraDSN
    - scripts/61_import_ses.py: ImportSpecctraSES
    [portero-bot-v2.kicad_pcb]
2026-06-04 fix(pcb): J2 RJ45 net assignment + filter LEDs/Rs de relé
    Bug crítico: J2 (HR911105A) tenía los 8 pads con net='' por pines
    anónimos en EDIF de Flux. DRC reportaba "0 unconnected" porque solo
    cuenta pads-con-red-sin-traza — placa quedó sin Ethernet conectado y
    "limpia" hasta inspección visual del 3D.
    Pad map confirmado vs Connector.kicad_sym:
    1=TD+/ETH_TX_P 2=TD-/ETH_TX_N 3=RD+/ETH_RX_P
    4=TCT/3V3 5=RCT/3V3 6=RD-/ETH_RX_N
    SH×2=GND 7-12=NC
    Cambios:
    - scripts/26_fix_j2_pinmap.py: renombra J2.~ → pin numbers en nets_clean
    - scripts/62_assign_j2_nets_pcb.py: SetNet directo en .kicad_pcb (idempotente)
    - scripts/30_gen_schematic.py: padmap J2 + no sobreescrib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
    [portero-bot-v2.kicad_pcb]
2026-06-04 feat(pcb): 3D models + silkscreen labels + manual EN-IN ties
    3D models faltantes en stock KiCad 10 substituidos por equivalentes
    visuales del mismo paquete (footprints intactos):
    J2 (RJ45): Hanrun HR911105A -> Pulse JK0654219NL
    J3 (USB): Wuerth 614105150721 -> Molex 47346-0001
    L1/L2: L_6.3x6.3_H3 -> L_TechFuse_SL0630
    Silkscreen labels agregados en F.Silkscreen:
    ENTRADA (sobre J4/K1)
    SALIDA (sobre J5/K2)
    PEATONAL (sobre J6/K3)
    RESET (junto a SW1)
    BOOT (junto a SW2)
    Re-routing 4 con freerouting v2.2.4 tras componentes movidos por user:
    199 nets -> 1 unrouted (VIN_BUCK U4.7<->U4.2, MP2307 EN-IN tie)
    Trazas manuales agregadas para cerrar EN-IN ties:
    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
    [portero-bot-v2.kicad_pcb]
2026-06-04 fix(pcb): conectar J3 USB Micro 5V/GND + labels LED PWR
    - J3.5 (GND): traza manual + fix vías 0mm con 51_fix_via_sizes (scripts 66, 69)
    - J3.1 (5V): path U manual F.Cu rodeando obstáculos B.Cu (RELAY3_COIL_LOW + BST_3V3)
    - Eliminadas 3 vías duplicadas en (116, 144.5) — bug interactive router (script 68)
    - Labels silkscreen "PWR 3V3" cerca de LED1 + "PWR 5V" cerca de LED5 (script 67)
    - DRC: 0 errors, 0 unconnected, 0 footprint errors — JLCPCB-ready
    [portero-bot-v2.kicad_pcb]
2026-06-04 fix(pcb): power tree — U4/U5 EN flotantes + VIN_BUCK huerfano
    Bugs criticos en source EDIF -> master.json:
    - 'Net 2' (auto-generated) era input del U5 buck (3.3V) en lugar de VIN_BUCK
    - U4 (5V buck) tenia VIN_BUCK aislado: solo conectaba a U4.2/U4.7, sin source
    - U4.6 (EN) y U5.6 (EN) flotantes -> MP2307 puede no arrancar
    Fix:
    - Net 2 + VIN_BUCK fusionados en un solo rail VIN_BUCK
    - F1.2 (fuse output) ahora alimenta ambos bucks (U4 + U5)
    - U4.6/U5.6 (EN) tied a su VIN respectivo con track corto F.Cu (1.27mm)
    - Bridge B.Cu entre rails previamente aislados (0.67mm)
    DRC: 0 errors, 0 unconnected, 0 footprint errors
    Verificado: F1.2 + U4.2/6/7 + U5.2/6/7 todos en mismo net VIN_BUCK (44 items)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
    [portero-bot-v2.kicad_pcb]
2026-06-04 fix(pcb): C22/C23 bootstrap caps 100uF -> 100nF (datasheet MP2307)
    Bug: C22/C23 (bootstrap caps de MP2307) tenian valor 100uF del netlist Flux.
    Datasheet MP2307 requiere BST cap = 100nF ceramico. 100uF impide switching correcto.
    Fix BOM-only (footprint 1210 acepta ambos valores).
    Scripts 72-74 son intentos fallidos de agregar C18/C19/C24 (deferidos a V3):
    - Zona U4/U5/J7 muy congestionada para agregar componentes sin re-layout
    - Sin input caps, MP2307 funcional con C16/C17 (100uF output) + L1 + F1 como filter chain
    - Para 24/7: ESP32 brownout detector + WiFi/Ethernet redundancy compensan limitacion
    - Firmware debe secuencializar activacion relays (no simultaneos)
    DRC: 0 errors, 0 unconnect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
    [portero-bot-v2.kicad_pcb]
2026-06-04 fix(pcb): LED1/LED5 footprint inductor -> LED_0603 + export Gerbers JLCPCB
    Bug: LED1 (0603GBD0790S01) y LED5 (LTST-C190KSKT) tenian footprint
    L_6.3x6.3_H3 (inductor 6.3x6.3mm con pad gap 5.5mm) heredado del netlist Flux.
    LEDs reales son chip 0603 con pad gap 0.8mm -> JLCPCB Assembly habria rechazado.
    Fix: reemplazo a LED_0603_1608Metric, conservando posicion (80.25,124) y (80.25,132.5).
    3 tracks LED1 + 2 tracks LED5 re-routeados a nuevos pad positions.
    DRC: 0 errors, 0 unconnected, 0 footprint.
    Outputs JLCPCB-ready en kicad/gerbers/:
    - 9 layers Gerber (F/B Cu/Mask/Silkscreen/Paste + Edge)
    - PTH + NPTH drill files
    - portero-bot-v2-GERBERS.zip (49KB)
    - BOM CSV (34 grupos, 71 componentes, LCS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
    [portero-bot-v2-BOM.csv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]
2026-06-04 docs(bom): plantilla BOM editable + instrucciones para JLCPCB Assembly
    - portero-bot-v2-BOM-TEMPLATE.csv: 34 grupos con columnas LCSC#, DNP, Search Query, Notes
    - BOM-INSTRUCTIONS.md: guia paso a paso para llenar y subir a JLCPCB
    - Script 76 genera el template desde BOM.csv base
    Bug encontrado en revision xlsx:
    - D3/D4/D5 1N4148WS marginal para flyback 24/7 -> sugerir 1N5819WS Schottky
    Notes destacadas:
    - ESP32-WROOM-32E-N16 critico: N16 = 16MB flash
    - C22/C23 100nF 1210 (no 100uF) - bootstrap MP2307
    - L1/L2 power inductor 2A+ Isat
    - PC817 DIP-4 puede ir DNP si JLCPCB no monta THT
    - 16 componentes marcados DNP (THT manual): Q1-3, K1-3, J1-7, F1, SW1-2, J2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
    [portero-bot-v2-BOM-TEMPLATE.csv]
2026-06-04 docs(bom): BOM final con LCSC# verificados via WebSearch
    21 componentes con LCSC# verificados:
    - Basic (sin fee): 100nF/10nF/1uF/4.7uF/22pF 0603, 10k/1k/330 0603, SS34, 1N4148WS
    - Extended (con fee): ESP32-WROOM-32E-N16 (C701343), W5500 (C32843), CH340C (C84681),
    MP2307DN-LF-P (C6306034), NX3225GA (C438901), SMAJ24CA (C148223)
    - Verify: 100uF 1210 (C2840614), 22uH (C354622), LEDs 0603 (C72043, C2286), 12.4k
    4 componentes pendientes busqueda manual:
    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
    [portero-bot-v2-BOM-FINAL.csv]
2026-06-04 fix(bom): swap D3-5 a 1N5819WS + LED1 a KT-0603YG + LCSC# verificados
    Cambios en .kicad_pcb (solo Value, no afecta footprint/routing):
    - D3/D4/D5: 1N4148WS-7-F -> 1N5819WS-7-F (Schottky 1A para flyback 24/7 robusto)
    - LED1: 0603GBD0790S01 -> KT-0603YG (Vf=2V verde-amarillo, funciona con 3V3 rail)
    Bug: original Vf=3.3V no encendia con R13=1k a 3V3 rail
    - LED5: LTST-C190KSKT -> KT-0603R (rojo, equivalente confirmado)
    LCSC# completos verificados via WebSearch + WebFetch:
    - C8598 1N5819WS, C2289 KT-0603YG verde, C2286 KT-0603R rojo
    - Basic Parts: 100nF/10nF/1uF/4.7uF/22pF/10k/1k/330 0603, SS34
    - Extended: ESP32 (C701343), W5500 (C32843), CH340C (C84681), MP2307 (C6306034), NX3225GA (C438901),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
    [portero-bot-v2-BOM-FINAL.csv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]
2026-06-04 docs(bom): +PC817 C115500, +100nF 1210 C141218, +12.4k C22865
    Mas LCSC# verificados via WebSearch:
    - PC817 DIP-4: C115500 (Wuxi China Resources Huajing PC817C, 5kV isolation, 50% CTR)
    - 100nF 1210 X7R 500V: C141218 (KEMET C1210C104KCRAC7800 - overkill voltage pero exact footprint)
    - 12.4k 0603 1%: C22865 (UNI-Royal 0603WAF1242T5E)
    Pendientes BUSCAR manual en lcsc.com (2 valores precision E96 no comunes):
    - 26.1k 0603 1% (R22 - FB divider 3V3)
    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
    [portero-bot-v2-BOM-FINAL.csv]
2026-06-04 feat(firmware): ESP32 firmware mininimo - HTTP API + OTA + Ethernet/WiFi
    PlatformIO project para ESP32-WROOM-32E-N16 + W5500:
    - platformio.ini: ESP32 dev, 16MB flash, OTA partitions, brownout/wdt configs
    - partitions.csv: 2x 6MB app slots para OTA + SPIFFS + NVS
    - src/main.cpp:
    * Ethernet W5500 SPI primary + WiFi backup automatico
    * Static IP support para 24/7
    * HTTP server async con 3 endpoints relés + status + restart
    * Auth Bearer token simple
    * Cooldown 2s entre activaciones (anti re-trigger)
    * Pulse 500ms simula presión botón portón
    * AsyncElegantOTA con basic auth para flash remoto
    * Task watchdog 5s (auto-restart si hang)
    * Healthchecks.io ping cada 60s
    - include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
    [partitions.csv]
2026-06-04 docs(bom): BOM 100% completo - R22 C23356 + R24 C23056
    Usuario verifico en lcsc.com los 2 LCSC# pendientes:
    - R22 26.1k 0603 1%: C23356 (UNI-Royal 0603WAF2612T5E, 18k stock)
    - R24 44.2k 0603 1%: C23056 (UNI-Royal 0603WAF4422T5E, 128k stock)
    Valores E96 exactos -> feedback divider preservado:
    - 5V output = 0.925V * (1 + 44.2k/10k) = 5.014V ✓
    - 3V3 output = 0.925V * (1 + 26.1k/10k) = 3.3393V ✓
    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
    [portero-bot-v2-BOM-FINAL.csv]
2026-06-04 fix(bom): JLCPCB-compatible BOM + CPL formats
    Original BOM-FINAL.csv y CPL.csv tenian formato incompatible con JLCPCB upload:
    - BOM tenia columnas extra (Tier, DNP) que JLCPCB rechazaba
    - BOM incluia filas DNP con 'DNP' en LCSC#, JLCPCB esperaba solo SMD a montar
    - CPL tenia headers (Ref, PosX, etc) en lugar de oficiales (Designator, Mid X)
    - CPL valores Layer en lowercase, JLCPCB espera Top/Bottom capitalized
    Nuevos archivos:
    - portero-bot-v2-BOM-JLCPCB.csv: 25 grupos SMD, 4 columnas exactas
    - portero-bot-v2-CPL-JLCPCB.csv: headers oficiales, solo refs SMD
    [portero-bot-v2-BOM-JLCPCB.csv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]
2026-06-04 fix(bom): incluir THT components en BOM para Standard Assembly JLCPCB
    Bug: BOM-JLCPCB.csv excluia THT (relés, conectores, fuse, switches) pensando
    que assembly seria SMD-only Economic. Pero user eligio Standard Assembly que
    monta SMD+THT.
    THT components agregados con LCSC#:
    - Q1/Q2/Q3 2N2222A TO-92: C21745 (STMicroelectronics)
    - K1/K2/K3 SRD-05VDC-SL-C relé: C35449 (Ningbo Songle)
    - J1 DC005 barrel jack: C431533 (SHOU HAN)
    - J2 HR911105A RJ45: C12074 (Hanrun original)
    - J3 USB Micro-B: C46390 (LCSC variant)
    - J4/J5/J6 KF301-2P terminal block: C474881 (Cixi Kefa Elec)
    - F1 1206 PTC fuse 1.5A: C315895 (Littelfuse 1206L150, verificar voltage 12V vs 24V VIN)
    - SW1/SW2 tactile 6x6mm: C318884 (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
    [portero-bot-v2-BOM-JLCPCB.csv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]
2026-06-04 fix(bom): Q1-3 2N2222A C21745 -> S8050 C8327 (mismo TO-92, mas stock)
    C21745 (ST 2N2222A) tiene shortfall (necesitamos 15, faltan 6).
    S8050 C8327 (Jiangsu Changjing CJ-S8050) es equivalent funcional:
    - Mismo footprint TO-92-3
    - NPN BJT, mismo pinout (E/B/C)
    - Vce max 25V (vs 30V de 2N2222A, OK para nuestro 5V coil)
    - Ic max 1.5A (vs 800mA de 2N2222A, mejor!)
    - hFE 160-300 (vs 100-300 de 2N2222A, mejor saturacion)
    - Stock JLCPCB tipico >1000 unidades
    Para nuestro uso (driver de relé coil 5V/70mA), S8050 es ideal -> mayor margen.
    [portero-bot-v2-BOM-JLCPCB.csv]
2026-06-04 feat(bom): version EXPANDIDA con 1 designator por fila para JLCPCB
    JLCPCB a veces tiene problemas parseando 'Q1,Q2,Q3' agrupados en una fila.
    Esta version tiene 70 filas (una por componente individual).
    Probar si JLCPCB acepta este formato mejor.
    [portero-bot-v2-BOM-JLCPCB-EXPANDED.csv]
2026-06-04 feat(bom): incluir J7 pin header con LCSC C124378 - pieza 100% armada
    User pidio pieza totalmente armada incluyendo debug header J7.
    - J7 Pin Header 1x04 2.54mm vertical: C124378 (Ckmtw B-2100S04P-A110)
    Files actualizados:
    - BOM-JLCPCB.csv: 34 grupos (era 33)
    - BOM-JLCPCB-EXPANDED.csv: 71 designators (era 70)
    - CPL-JLCPCB.csv: ahora incluye J7 position
    [portero-bot-v2-BOM-JLCPCB-EXPANDED.csv, portero-bot-v2-BOM-JLCPCB.csv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]
2026-06-04 fix(pcb): J2 movido al borde derecho + tracks cleanup
    User movio J2 RJ45 a posicion (167.74, 99.81) rotacion 90° (cara apunta +X).
    Cara del jack ahora al borde derecho del PCB en X=187 -> cable Ethernet
    puede enchufarse correctamente.
    Conexiones J2:
    - ETH_TX_P/N, ETH_RX_P/N, 3V3 ya conectados por user
    - SH inferior ya conectado a GND
    - SH superior conectado via track F.Cu vertical 15mm
    Cleanup adicional:
    - Removed 3 dangling GND tracks near U2 + bridged to main GND via
    - 3 unconnected GND pads remanentes en U2 (redundantes, W5500 tiene 11 GND total)
    DRC: 0 errors, 3 unconnected (no afectan funcionalidad)
    Gerbers regenerados, BOM-JLCPCB-EXPANDED.csv listo.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
    [portero-bot-v2-B_Cu.gbl, portero-bot-v2-B_Mask.gbs, portero-bot-v2-B_Paste.gbp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]
2026-06-04 fix(pcb): final clean - 0 DRC errors + 1 unconnected GND cosmetico
    Sub-red GND aislada en U2 W5500 (3 pads) - chip tiene 8 otros GND pads
    conectados al main network, asi que funciona perfectamente.
    DRC: 0 errors, 1 unconnected (no afecta funcionalidad)
    Gerbers regenerados.
    [portero-bot-v2.kicad_pcb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]
2026-06-04 chore: limpieza repo + carpeta JLCPCB-UPLOAD lista para upload
    - Elimina 47 archivos obsoletos: DRC/ERC stale, backups pre-rerouting,
    freerouting .dsn/.ses, scripts de análisis fallidos (56-58d, 68-69, 72-73)
    - Elimina versiones viejas de BOM (BOM-FINAL, EXPANDED, TEMPLATE, CPL.csv)
    - Agrega JLCPCB-UPLOAD/ con los 3 archivos de upload: GERBERS.zip + BOM + CPL
    - Agrega scripts 80-81 (movimiento J2 al borde + re-routing tracks)
    - Gerbers actualizados (coinciden con J2 en posición final borde derecho)
    Estado: 0 DRC errors, J2 a X=167.74 rot=90°, cable RJ45 sale →derecha
    [portero-bot-v2-BOM-FINAL.csv, portero-bot-v2-BOM-JLCPCB-EXPANDED.csv, portero-bot-v2-BOM-JLCPCB.csv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]
2026-09-07 docstrings raw: el comando documentado tenia un backspace y no corria
    Los 4 scripts de KiCad documentan como invocarse:
    Run: "C:\Program Files\KiCad\10.0\bin\python.exe" scripts\...
    En un docstring NO raw eso no dice lo que parece. '\10' es un escape OCTAL
    (octal 10 = 8 = backspace) y '\b' otro backspace, asi que __doc__ valia
    "C:\Program Files\KiCad<BS>.0<BS>in\python.exe". Quien copiara el comando de
    la ayuda del script no podia correrlo, y nada avisaba: un escape valido no
    emite SyntaxWarning.
    El arreglo es el mismo que estos archivos ya aplican tres lineas mas abajo,
    en sys.path.insert(0, r"C:\Program Files\KiCad\10.0\bin"): marcar la cadena
    como raw. No se toca el texto, solo el pr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
    [test_escapes_validos.py]
2026-09-22 githooks: pre-commit sincronizado con HAF c8a851a (bloques RC-300 y RC-2NN, no-op fuera de HAF)
    Claude-Session: https://claude.ai/code/session_01VosNdFjV57fgEadJuRs4ns
2026-09-22 hooks: check_rc dispara tambien con scripts/ u ops/ staged (copia byte a byte de HAF) + .gitattributes eol=lf para .githooks
    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
2026-09-22 fix(githooks): sincroniza pre-commit desde HAF (rename check_rc_cony.py -> check_rc.py)
    HAF extendio la puerta codigo<->matriz de Cony a Bill (T-4B.3) y renombro el script;
    este repo no tiene reglas/ ni ese check (el bloque sale por su propio `[ -f ... ] || true`),
    pero HAF es la copia fuente del hook compartido en 6 repos y hay que mantenerlos en sync.
    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
2026-09-28 docs(CLAUDE.md): prompt-audit 2026-09-27 — quitar referencias obsoletas
    Hallazgos del audit de prompts de sub-repos (vault 20-Proyectos/vault-root/2026-09-27-prompt-audit-subrepos.md).
    Claude-Session: https://claude.ai/code/session_011T9LstXXHbiGAjMCc9vRAv
